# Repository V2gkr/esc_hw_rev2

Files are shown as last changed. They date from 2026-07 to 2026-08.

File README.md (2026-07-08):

# ESC HW Rev2 - E-Bike BLDC Motor Driver

Rev2 hardware for an electronic speed controller (ESC) for an e-bike. Designed in KiCad.

## Key Specifications

| Parameter | Value |
|---|---|
| Nominal battery voltage | 36 V |
| Nominal motor power | 250 W |
| MCU | STM32G431CBT6 |
| Gate driver | DRV8320S |
| Phase current sensing |  low-side shunts |
| Rotor position feedback | Hall sensors |
| Interfaces | CAN FD, UART |
| Indication | LEDs (Green / Red) |
| Control | Reset button |

## Board Architecture

The project is split into several KiCad hierarchical schematic sheets:

- **MCU.kicad_sch** - STM32G431CBT6 support circuitry: power supply, crystals, debug interface, reset button, LEDs.
- **Power.kicad_sch** - 36 V input power stage, protection, DC/DC converters for logic and gate driver supply.
- **Inverter.kicad_sch** - three-phase power inverter stage based on DRV8320S and power MOSFETs.
- **Measurements.kicad_sch** - phase current sensing circuitry (3 low-side shunts) and Hall sensor interfaces.
- **CAN.kicad_sch** - CAN FD transceiver and supporting circuitry.
- **BLDC_Test.kicad_sch / BLDC_Test.kicad_pcb / BLDC_Test.kicad_pro** - top-level schematic and PCB layout tying all sheets above together.

## Key Subsystems

### Power Stage
Three-phase MOSFET inverter driven by the **DRV8320S** gate driver (built-in protection: overtemperature, overcurrent, gate drive undervoltage, etc.).

### Current and Rotor Position Sensing
- 3 low-side shunts - phase current measurement for FOC/trapezoidal commutation and overcurrent protection.
- Hall sensors - rotor position detection for low-speed commutation and start-up under load.

### Communication Interfaces
- **CAN FD** - primary control/telemetry channel (e.g. integration with a BMS or a central e-bike controller).
- **UART** - debugging, logging, alternative control/flashing channel.

### Indication and Control
- Green / Red LEDs - status indication (ready, fault, CAN activity, etc. â€” defined by firmware).
- Reset button - hardware MCU reset.

## Project Status

Hardware only (rev2). Firmware is maintained in a separate repository (see [`esc_fw_rev2`](https://github.com/V2gkr/esc_fw_rev2/tree/main)).

## TODO
- [ ] Export schematics to PDF for quick viewing without KiCad
- [ ] Bill of Materials (BOM)
- [ ] Board photos/renders
- [ ] Datasheet links for key components (DRV8320S, STM32G431CBT6)

## Tools
Designed in **KiCad**.

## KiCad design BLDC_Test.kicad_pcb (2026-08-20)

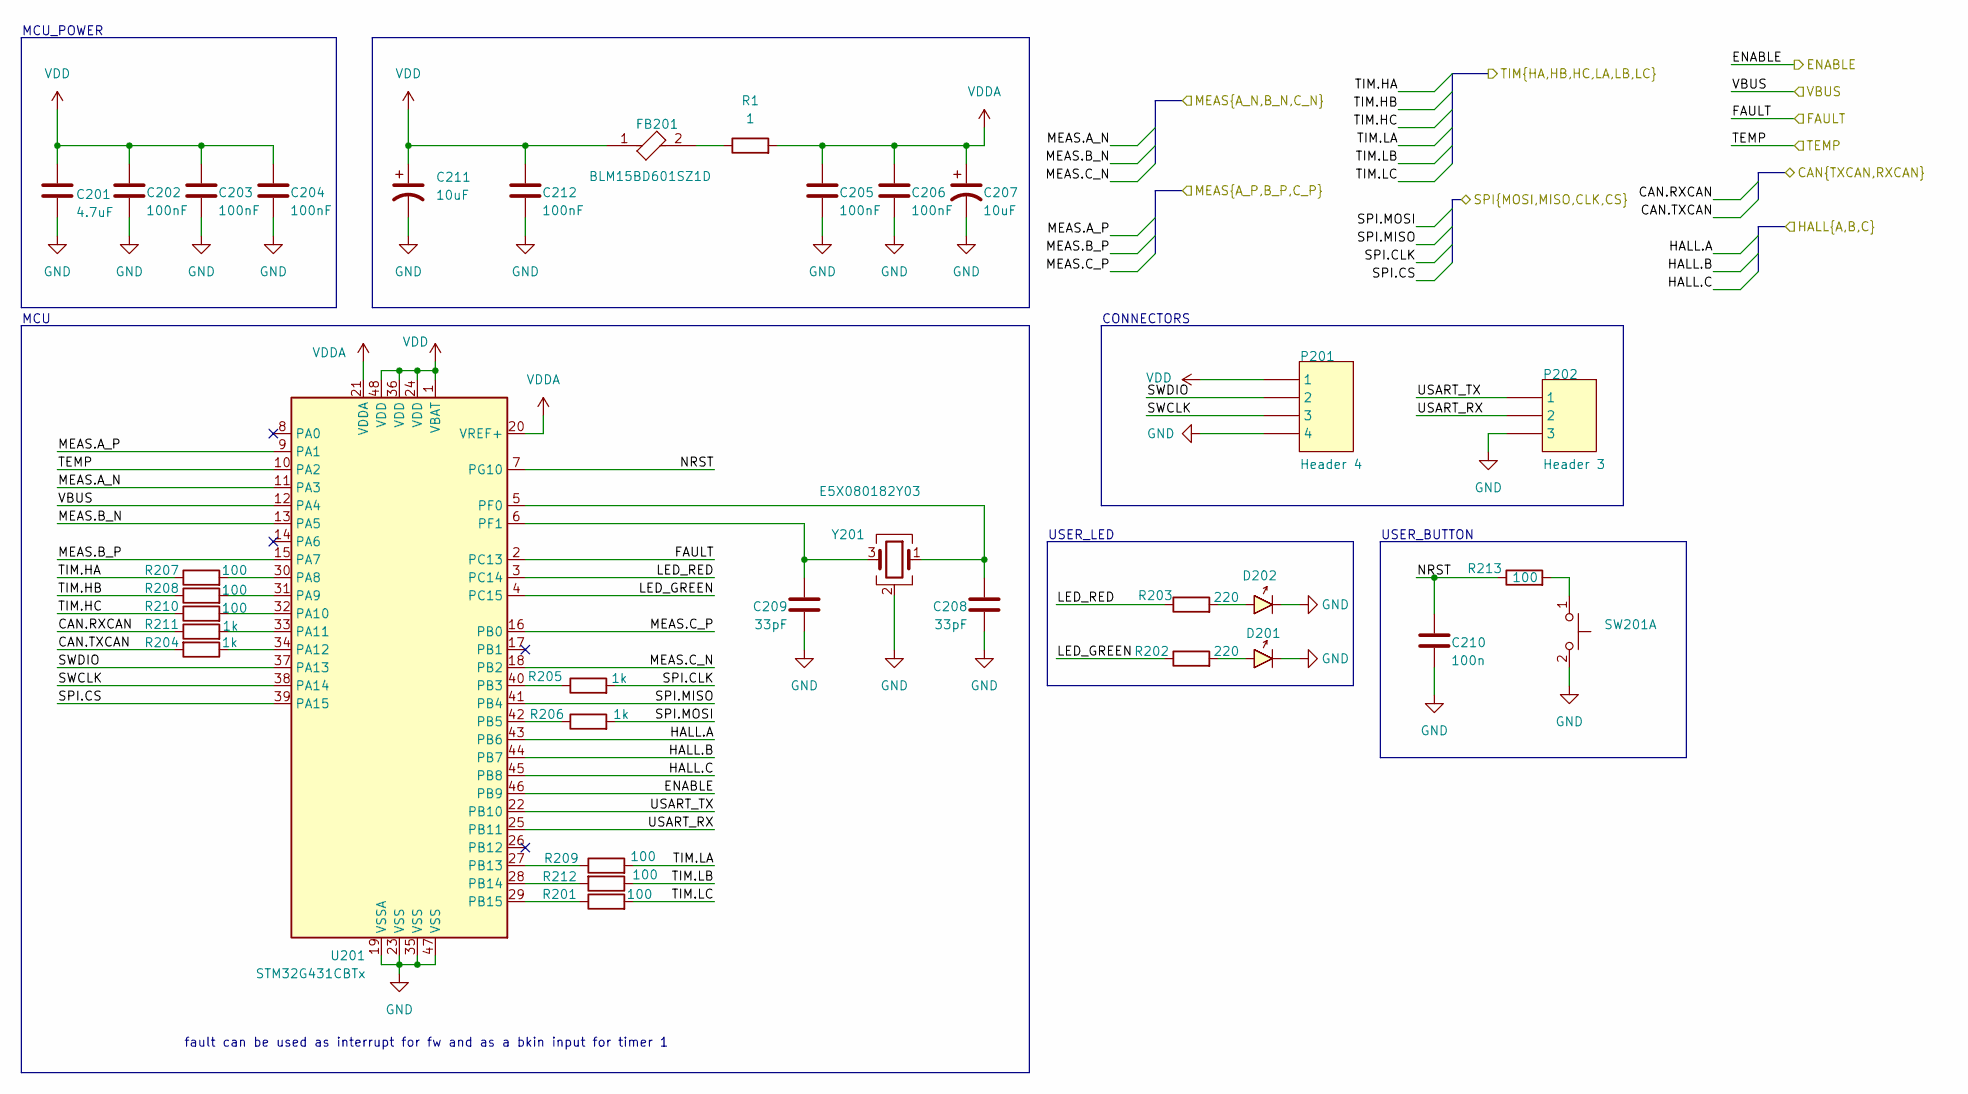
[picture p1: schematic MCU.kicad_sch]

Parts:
C201: 4.7uF; C_0603_1608Metric_Pad1.08x0.95mm_HandSolder
C202, C203, C204, C205, C206, C212: 100nF; C_0603_1608Metric_Pad1.08x0.95mm_HandSolder
C207, C211: 10uF; CP_EIA-2012-15_AVX-P_HandSolder
C208, C209: 33pF; C_0603_1608Metric_Pad1.08x0.95mm_HandSolder
C210: 100n; C_0603_1608Metric_Pad1.08x0.95mm_HandSolder
D201, D202: Common diode; LED_0603_1608Metric_Pad1.05x0.95mm_HandSolder; REVERSE VOLTAGE 1000V; MANUFACTURER PART NUMBER US1M-E3/61T; DIGIKEY DESCRIPTION DIODE GEN PURP 1KV 1A DO214AC
FB201: BLM15BD601SZ1D; L_0603_1608Metric_Pad1.05x0.95mm_HandSolder
P201: Header 4; PinHeader_1x04_P2.54mm_Vertical
P202: Header 3; PinHeader_1x03_P2.54mm_Vertical
R1: 1; R_0603_1608Metric_Pad0.98x0.95mm_HandSolder
R201, R207, R208, R209, R210, R212, R213: 100; R_0603_1608Metric_Pad0.98x0.95mm_HandSolder
R202, R203: 220; R_0603_1608Metric_Pad0.98x0.95mm_HandSolder
R204, R205, R206, R211: 1k; R_0603_1608Metric_Pad0.98x0.95mm_HandSolder
SW201: PTS647SM38SMTR2LFS; SW_SPST_TL3305A; RATINGS IP40
U201: STM32G431CBTx; LQFP-48_7x7mm_P0.5mm
Y201: E5X080182Y03; Crystal_SMD_WE_CFPX-104-4Pin_5.0x3.2mm; FREQUENCY TOLERANCE 0.07%

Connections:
/can/CAN.RXCAN: R211.1; also elsewhere on the board
/can/CAN.TXCAN: R204.2; also elsewhere on the board
/inverter/ENABLE: U201.46 (PB9); also elsewhere on the board
/inverter/FAULT: U201.2 (PC13); also elsewhere on the board
/inverter/MEAS.A_N: U201.11 (PA3); also elsewhere on the board
/inverter/MEAS.B_N: U201.13 (PA5); also elsewhere on the board
/inverter/MEAS.C_N: U201.18 (PB2); also elsewhere on the board
/inverter/SPI.CLK: R205.2; also elsewhere on the board
/inverter/SPI.CS: U201.39 (PA15); also elsewhere on the board
/inverter/SPI.MISO: U201.41 (PB4); also elsewhere on the board
/inverter/SPI.MOSI: R206.2; also elsewhere on the board
/inverter/TIM.HA: R207.1; also elsewhere on the board
/inverter/TIM.HB: R208.1; also elsewhere on the board
/inverter/TIM.HC: R210.1; also elsewhere on the board
/inverter/TIM.LA: R209.2; also elsewhere on the board
/inverter/TIM.LB: R212.1; also elsewhere on the board
/inverter/TIM.LC: R201.2; also elsewhere on the board
/mcu/HALL.A: U201.43 (PB6); also elsewhere on the board
/mcu/HALL.B: U201.44 (PB7); also elsewhere on the board
/mcu/HALL.C: U201.45 (PB8); also elsewhere on the board
/mcu/LED_GREEN: R202.1, U201.4 (PC15)
/mcu/LED_RED: R203.1, U201.3 (PC14)
/mcu/MEAS.A_P: U201.9 (PA1); also elsewhere on the board
/mcu/MEAS.B_P: U201.15 (PA7); also elsewhere on the board
/mcu/MEAS.C_P: U201.16 (PB0); also elsewhere on the board
/mcu/NRST: C210.1, R213.1, U201.7 (PG10)
/mcu/SWCLK: P201.3, U201.38 (PA14)
/mcu/SWDIO: P201.2, U201.37 (PA13)
/mcu/TEMP: U201.10 (PA2); also elsewhere on the board
/mcu/USART_RX: P202.2, U201.25 (PB11)
/mcu/USART_TX: P202.1, U201.22 (PB10)
/mcu/VBUS: U201.12 (PA4); also elsewhere on the board
GND: C201.2, C202.2, C203.2, C204.2, C205.2, C206.2, C207.2, C208.2, C209.2, C210.2, C211.2, C212.2, D201.1 (C), D202.1 (C), P201.4, P202.3, SW201.2 (D), U201.19 (VSSA), U201.23 (VSS), U201.35 (VSS), U201.47 (VSS), Y201.2 (G), Y201.4 (G); also elsewhere on the board
unnamed: D201.2 (A), R202.2
unnamed: D202.2 (A), R203.2
unnamed: FB201.2, R1.1
unnamed: R213.2, SW201.1 (C)
unnamed: R207.2, U201.30 (PA8)
unnamed: R208.2, U201.31 (PA9)
unnamed: R210.2, U201.32 (PA10)
unnamed: R211.2, U201.33 (PA11)
unnamed: R204.1, U201.34 (PA12)
unnamed: R205.1, U201.40 (PB3)
unnamed: R206.1, U201.42 (PB5)
unnamed: R209.1, U201.27 (PB13)
unnamed: R212.2, U201.28 (PB14)
unnamed: R201.1, U201.29 (PB15)
unnamed: C208.1, U201.5 (PF0), Y201.1
unnamed: C209.1, U201.6 (PF1), Y201.3
VDD: C201.1, C202.1, C203.1, C204.1, C211.1, C212.1, FB201.1, P201.1, U201.1 (VBAT), U201.24 (VDD), U201.36 (VDD), U201.48 (VDD); also elsewhere on the board
VDDA: C205.1, C206.1, C207.1, R1.2, U201.20 (VREF+), U201.21 (VDDA); also elsewhere on the board

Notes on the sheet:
USER_LED
MCU_POWER
CONNECTORS
USER_BUTTON
MCU
fault can be used as interrupt for fw and as a bkin input for timer 1

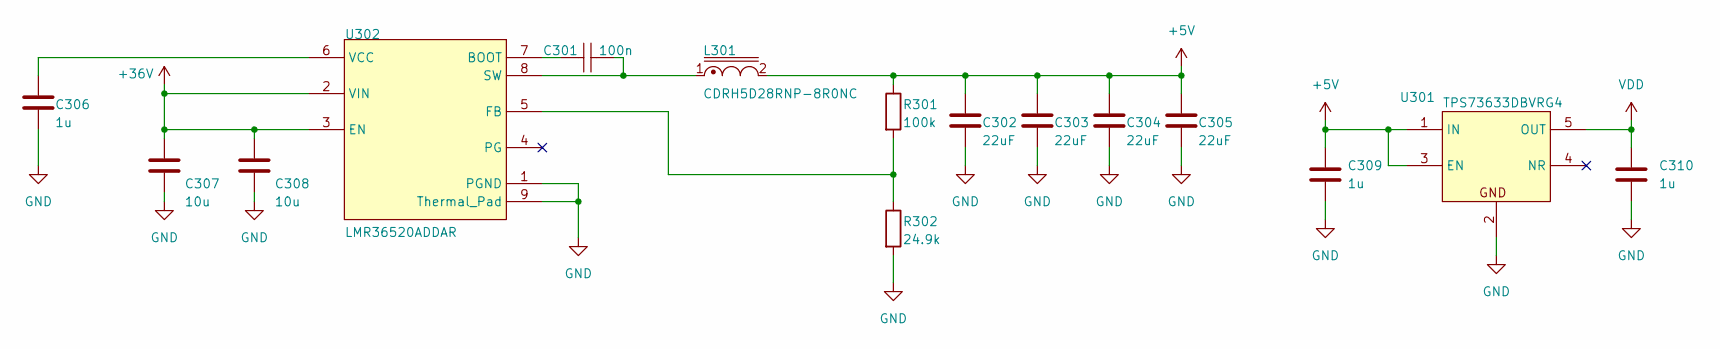
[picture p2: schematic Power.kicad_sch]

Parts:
C301: 100n; C_0603_1608Metric_Pad1.08x0.95mm_HandSolder
C302, C303, C304, C305: 22uF; C_0805_2012Metric_Pad1.18x1.45mm_HandSolder
C306, C309, C310: 1u; C_0603_1608Metric_Pad1.08x0.95mm_HandSolder
C307, C308: 10u; C_0805_2012Metric_Pad1.18x1.45mm_HandSolder
L301: CDRH5D28RNP-8R0NC; MANUFACTURER PART NUMBER PA4320.153NLT
R301: 100k; R_0603_1608Metric_Pad0.98x0.95mm_HandSolder
R302: 24.9k; R_0603_1608Metric_Pad0.98x0.95mm_HandSolder
U301: TPS73633DBVRG4; SOT-23-5_HandSoldering; RATING Catalog; PARTNUMBER TPS73633DBVRG4
U302: LMR36520ADDAR; FP-DDA0008J-IPC_B

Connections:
+5V: C302.1, C303.1, C304.1, C305.1, C309.1, L301.2, R301.1, U301.1 (IN), U301.3 (EN); also elsewhere on the board
+36V: C307.1, C308.1, U302.2 (VIN), U302.3 (EN); also elsewhere on the board
GND: C302.2, C303.2, C304.2, C305.2, C306.2, C307.2, C308.2, C309.2, C310.2, R302.2, U301.2 (GND), U302.1 (PGND), U302.9 (Thermal_Pad); also elsewhere on the board
unnamed: C301.2, U302.7 (BOOT)
unnamed: R301.2, R302.1, U302.5 (FB)
unnamed: C301.1, L301.1, U302.8 (SW)
unnamed: C306.1, U302.6 (VCC)
VDD: C310.1, U301.5 (OUT); also elsewhere on the board

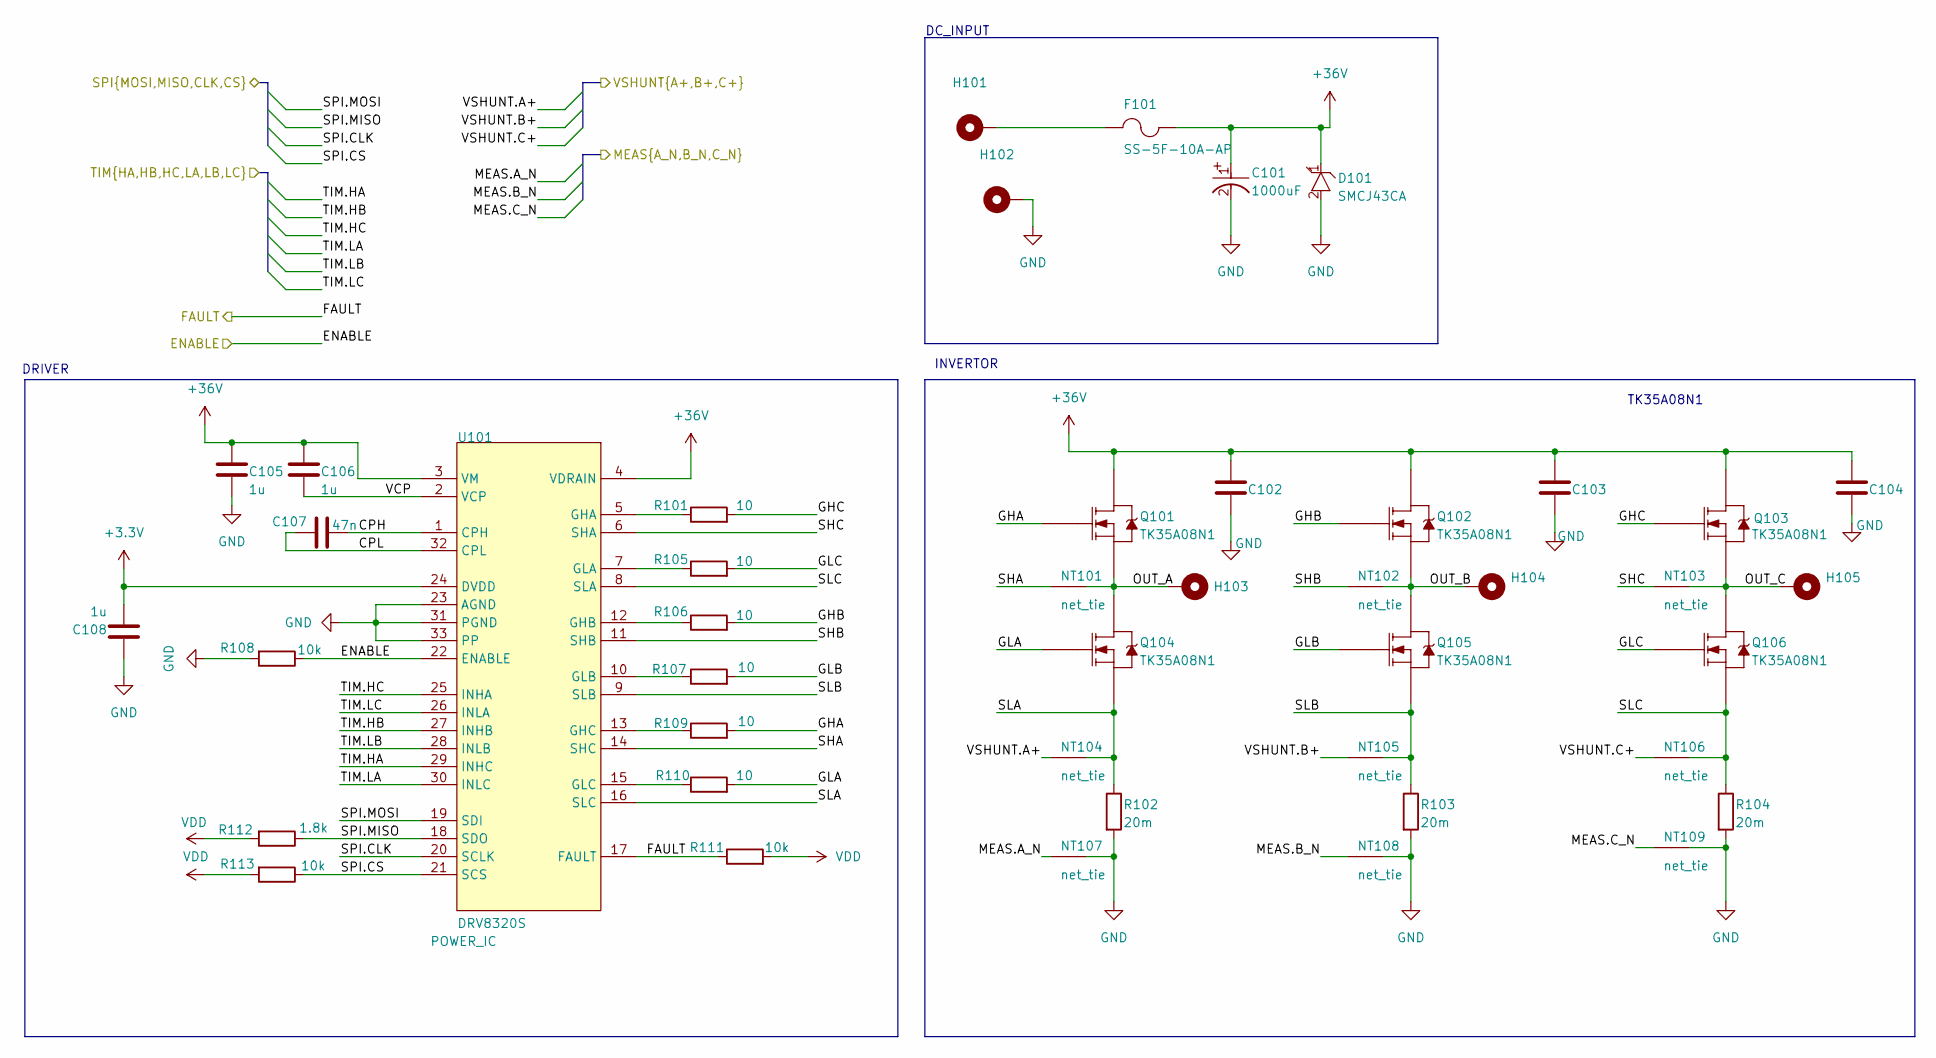
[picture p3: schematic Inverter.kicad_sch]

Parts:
C101: 1000uF; PCAP_7_5mm; VOLTAGE RATING (DC) 50V; TOLERANCE 20%; MANUFACTURER PART NUMBER EEUFM1H471
C102, C103, C104: 1812B105K101CT; C_1812_4532Metric_Pad1.57x3.40mm_HandSolder
C105: 1u; C_1210_3225Metric_Pad1.33x2.70mm_HandSolder
C106, C108: 1u; C_0603_1608Metric_Pad1.08x0.95mm_HandSolder
C107: 47n; C_0603_1608Metric_Pad1.08x0.95mm_HandSolder
D101: SMCJ43CA; D_SMC; REVERSE VOLTAGE 1000V; MANUFACTURER PART NUMBER US1M-E3/61T; DIGIKEY DESCRIPTION DIODE GEN PURP 1KV 1A DO214AC
F101: SS-5F-10A-AP; FUSE_SS-5F_COB; MANUFACTURER_PART_NUMBER SS-5F-1.25A-AP
H101, H102, H103, H104, H105: phase connector; phase_cable_soldering_hole
NT101, NT102, NT103: net_tie; NetTie-2_SMD_Pad0.5mm
NT104, NT105, NT106, NT107, NT108, NT109: net_tie; NetTie-2_SMD_Pad0.3mm
Q101, Q102, Q103, Q104, Q105, Q106: TK35A08N1; TO-220-3_Vertical
R101, R105, R106, R107, R109, R110: 10; R_0603_1608Metric_Pad0.98x0.95mm_HandSolder
R102, R103, R104: 20m; R_2512_6332Metric_Pad1.40x3.35mm_HandSolder
R108, R111, R113: 10k; R_0603_1608Metric_Pad0.98x0.95mm_HandSolder
R112: 1.8k; R_0603_1608Metric_Pad0.98x0.95mm_HandSolder
U101: DRV8320S; QFN50P500X500X80-33N

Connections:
+3.3V: C108.2, U101.24 (DVDD)
+36V: C101.1 (A), C102.1, C103.1, C104.1, C105.1, C106.1, D101.1 (C), F101.2, Q101.2 (D), Q102.2 (D), Q103.2 (D), U101.3 (VM), U101.4 (VDRAIN); also elsewhere on the board
/inverter/CPH: C107.2, U101.1 (CPH)
/inverter/CPL: C107.1, U101.32 (CPL)
/inverter/ENABLE: R108.1, U101.22 (ENABLE); also elsewhere on the board
/inverter/FAULT: R111.1, U101.17 (FAULT); also elsewhere on the board
/inverter/GHA: Q101.1 (G), R109.2
/inverter/GHB: Q102.1 (G), R106.2
/inverter/GHC: Q103.1 (G), R101.2
/inverter/GLA: Q104.1 (G), R110.2
/inverter/GLB: Q105.1 (G), R107.2
/inverter/GLC: Q106.1 (G), R105.2
/inverter/MEAS.A_N: NT107.2; also elsewhere on the board
/inverter/MEAS.B_N: NT108.2; also elsewhere on the board
/inverter/MEAS.C_N: NT109.2; also elsewhere on the board
/inverter/OUT_A: H103.1 (1_1), NT101.1, Q101.3 (S), Q104.2 (D)
/inverter/OUT_B: H104.1 (1_1), NT102.1, Q102.3 (S), Q105.2 (D)
/inverter/OUT_C: H105.1 (1_1), NT103.1, Q103.3 (S), Q106.2 (D)
/inverter/SHA: NT101.2, U101.14 (SHC)
/inverter/SHB: NT102.2, U101.11 (SHB)
/inverter/SHC: NT103.2, U101.6 (SHA)
/inverter/SLA: NT104.1, Q104.3 (S), R102.1, U101.16 (SLC)
/inverter/SLB: NT105.1, Q105.3 (S), R103.1, U101.9 (SLB)
/inverter/SLC: NT106.1, Q106.3 (S), R104.1, U101.8 (SLA)
/inverter/SPI.CLK: U101.20 (SCLK); also elsewhere on the board
/inverter/SPI.CS: R113.1, U101.21 (SCS); also elsewhere on the board
/inverter/SPI.MISO: R112.1, U101.18 (SDO); also elsewhere on the board
/inverter/SPI.MOSI: U101.19 (SDI); also elsewhere on the board
/inverter/TIM.HA: U101.29 (INHC); also elsewhere on the board
/inverter/TIM.HB: U101.27 (INHB); also elsewhere on the board
/inverter/TIM.HC: U101.25 (INHA); also elsewhere on the board
/inverter/TIM.LA: U101.30 (INLC); also elsewhere on the board
/inverter/TIM.LB: U101.28 (INLB); also elsewhere on the board
/inverter/TIM.LC: U101.26 (INLA); also elsewhere on the board
/inverter/VCP: C106.2, U101.2 (VCP)
/inverter/VSHUNT.A+: NT104.2; also elsewhere on the board
/inverter/VSHUNT.B+: NT105.2; also elsewhere on the board
/inverter/VSHUNT.C+: NT106.2; also elsewhere on the board
GND: C101.2 (B), C102.2, C103.2, C104.2, C105.2, C108.1, D101.2 (A), H102.1 (1_1), NT107.1, NT108.1, NT109.1, R102.2, R103.2, R104.2, R108.2, U101.23 (AGND), U101.31 (PGND), U101.33 (PP); also elsewhere on the board
unnamed: F101.1, H101.1 (1_1)
unnamed: R101.1, U101.5 (GHA)
unnamed: R106.1, U101.12 (GHB)
unnamed: R109.1, U101.13 (GHC)
unnamed: R105.1, U101.7 (GLA)
unnamed: R107.1, U101.10 (GLB)
unnamed: R110.1, U101.15 (GLC)
VDD: R111.2, R112.2, R113.2; also elsewhere on the board

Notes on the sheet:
TK35A08N1
INVERTOR
DRIVER
DC_INPUT

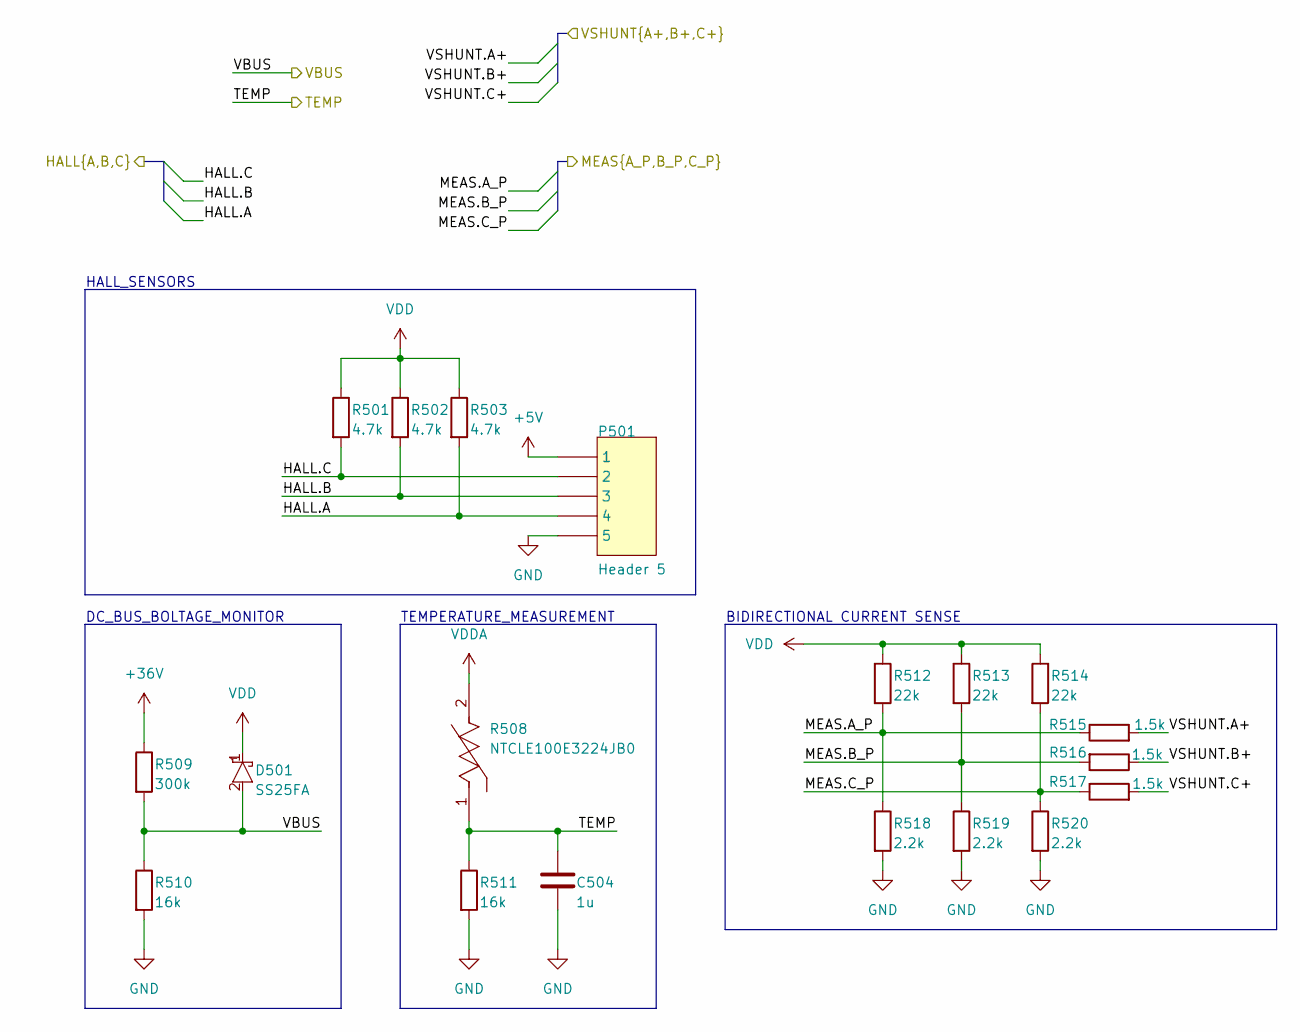
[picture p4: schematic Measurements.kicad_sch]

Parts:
C504: 1u; C_0603_1608Metric_Pad1.08x0.95mm_HandSolder
D501: SS25FA; D_SOD-323; REVERSE VOLTAGE 1000V; MANUFACTURER PART NUMBER US1M-E3/61T; DIGIKEY DESCRIPTION DIODE GEN PURP 1KV 1A DO214AC
P501: Header 5; PinHeader_1x05_P2.54mm_Vertical
R501, R502, R503: 4.7k; R_0603_1608Metric_Pad0.98x0.95mm_HandSolder
R508: NTCLE100E3224JB0; FP-NTCLE100E3224JB0-MFG; TOLERANCE 5%; RESISTANCE TOLERANCE 5%
R509: 300k; R_0603_1608Metric_Pad0.98x0.95mm_HandSolder
R510, R511: 16k; R_0603_1608Metric_Pad0.98x0.95mm_HandSolder
R512, R513, R514: 22k; R_0603_1608Metric_Pad0.98x0.95mm_HandSolder
R515, R516, R517: 1.5k; R_0603_1608Metric_Pad0.98x0.95mm_HandSolder
R518, R519, R520: 2.2k; R_0603_1608Metric_Pad0.98x0.95mm_HandSolder

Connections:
+5V: P501.1; also elsewhere on the board
+36V: R509.1; also elsewhere on the board
/inverter/VSHUNT.A+: R515.2; also elsewhere on the board
/inverter/VSHUNT.B+: R516.1; also elsewhere on the board
/inverter/VSHUNT.C+: R517.2; also elsewhere on the board
/mcu/HALL.A: P501.4, R503.2; also elsewhere on the board
/mcu/HALL.B: P501.3, R502.2; also elsewhere on the board
/mcu/HALL.C: P501.2, R501.2; also elsewhere on the board
/mcu/MEAS.A_P: R512.2, R515.1, R518.1; also elsewhere on the board
/mcu/MEAS.B_P: R513.2, R516.2, R519.1; also elsewhere on the board
/mcu/MEAS.C_P: R514.2, R517.1, R520.1; also elsewhere on the board
/mcu/TEMP: C504.1, R508.1, R511.1; also elsewhere on the board
/mcu/VBUS: D501.2 (A), R509.2, R510.1; also elsewhere on the board
GND: C504.2, P501.5, R510.2, R511.2, R518.2, R519.2, R520.2; also elsewhere on the board
VDD: D501.1 (C), R501.1, R502.1, R503.1, R512.1, R513.1, R514.1; also elsewhere on the board
VDDA: R508.2; also elsewhere on the board

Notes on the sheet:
HALL_SENSORS
DC_BUS_BOLTAGE_MONITOR
BIDIRECTIONAL CURRENT SENSE
TEMPERATURE_MEASUREMENT

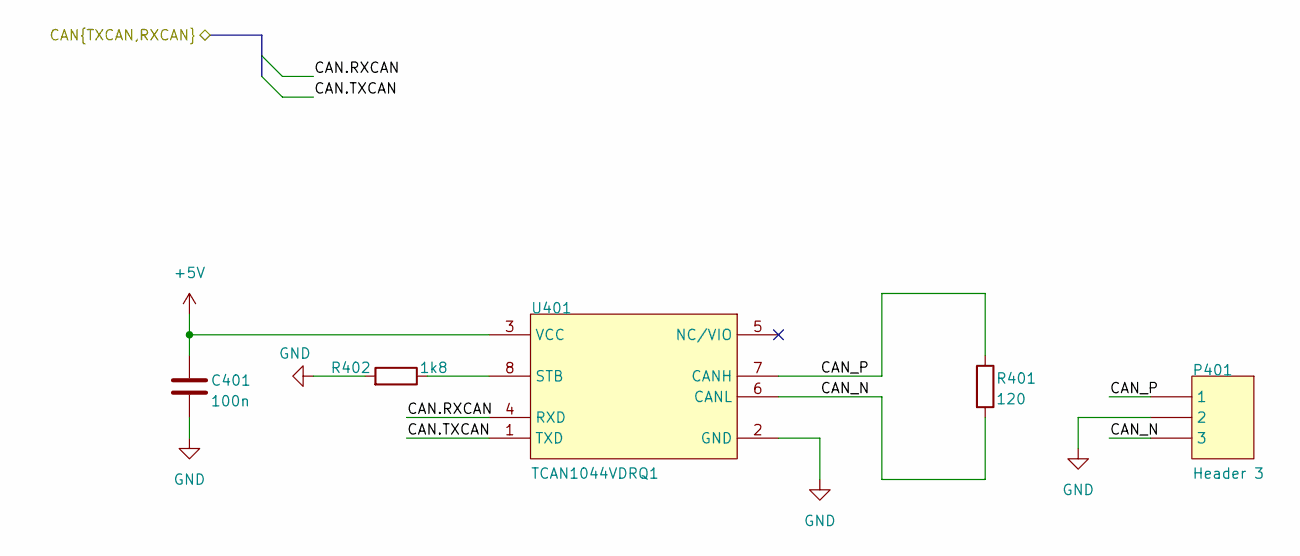
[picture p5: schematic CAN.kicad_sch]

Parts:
C401: 100n; C_0603_1608Metric_Pad1.08x0.95mm_HandSolder
P401: Header 3; PinHeader_1x03_P2.54mm_Vertical
R401: 120; R_0603_1608Metric_Pad0.98x0.95mm_HandSolder
R402: 1k8; R_0603_1608Metric_Pad0.98x0.95mm_HandSolder
U401: TCAN1044VDRQ1; SO-8_3.9x4.9mm_P1.27mm

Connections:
+5V: C401.1, U401.3 (VCC); also elsewhere on the board
/can/CAN.RXCAN: U401.4 (RXD); also elsewhere on the board
/can/CAN.TXCAN: U401.1 (TXD); also elsewhere on the board
/can/CAN_N: P401.3, R401.2, U401.6 (CANL)
/can/CAN_P: P401.1, R401.1, U401.7 (CANH)
GND: C401.2, P401.2, R402.2, U401.2 (GND); also elsewhere on the board
unnamed: R402.1, U401.8 (STB)

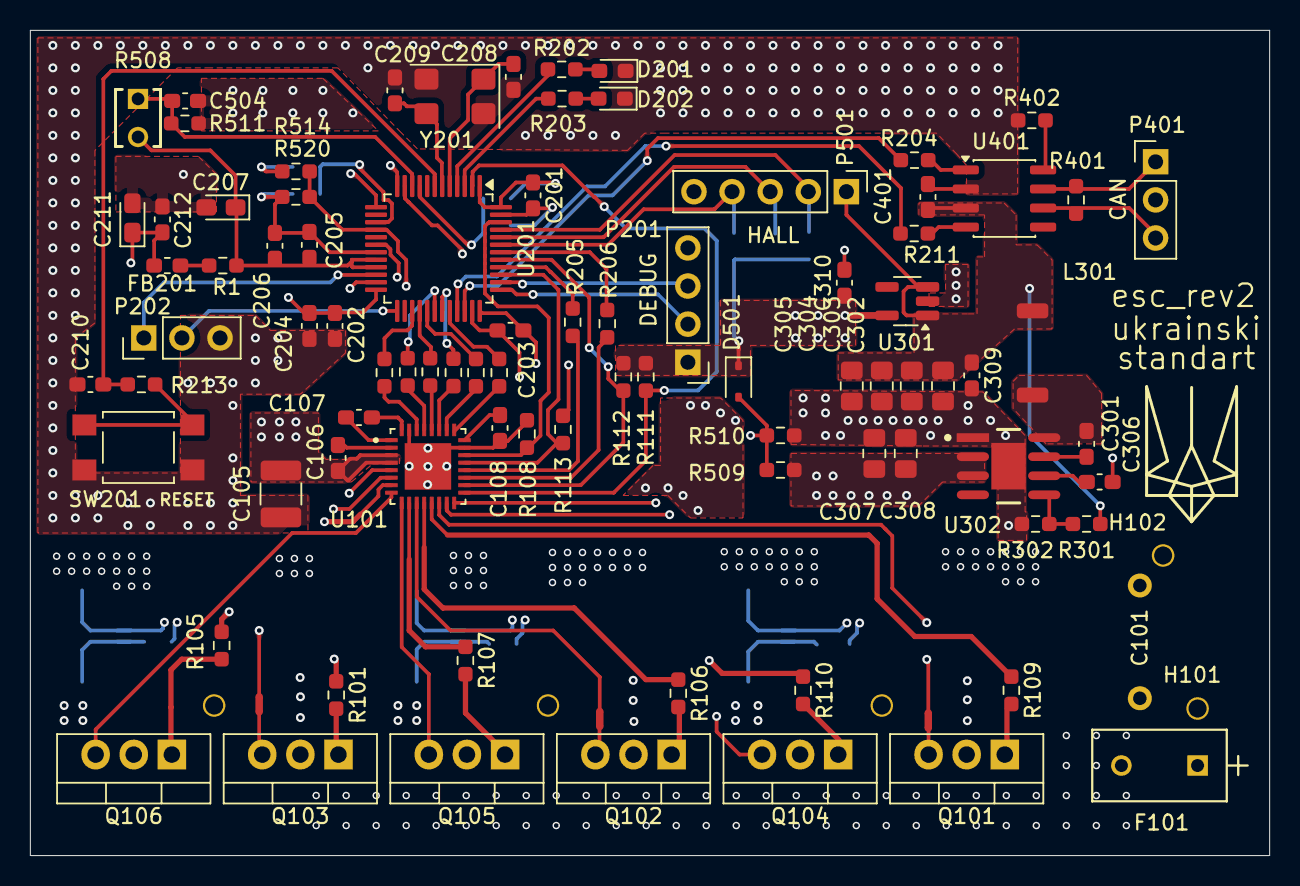
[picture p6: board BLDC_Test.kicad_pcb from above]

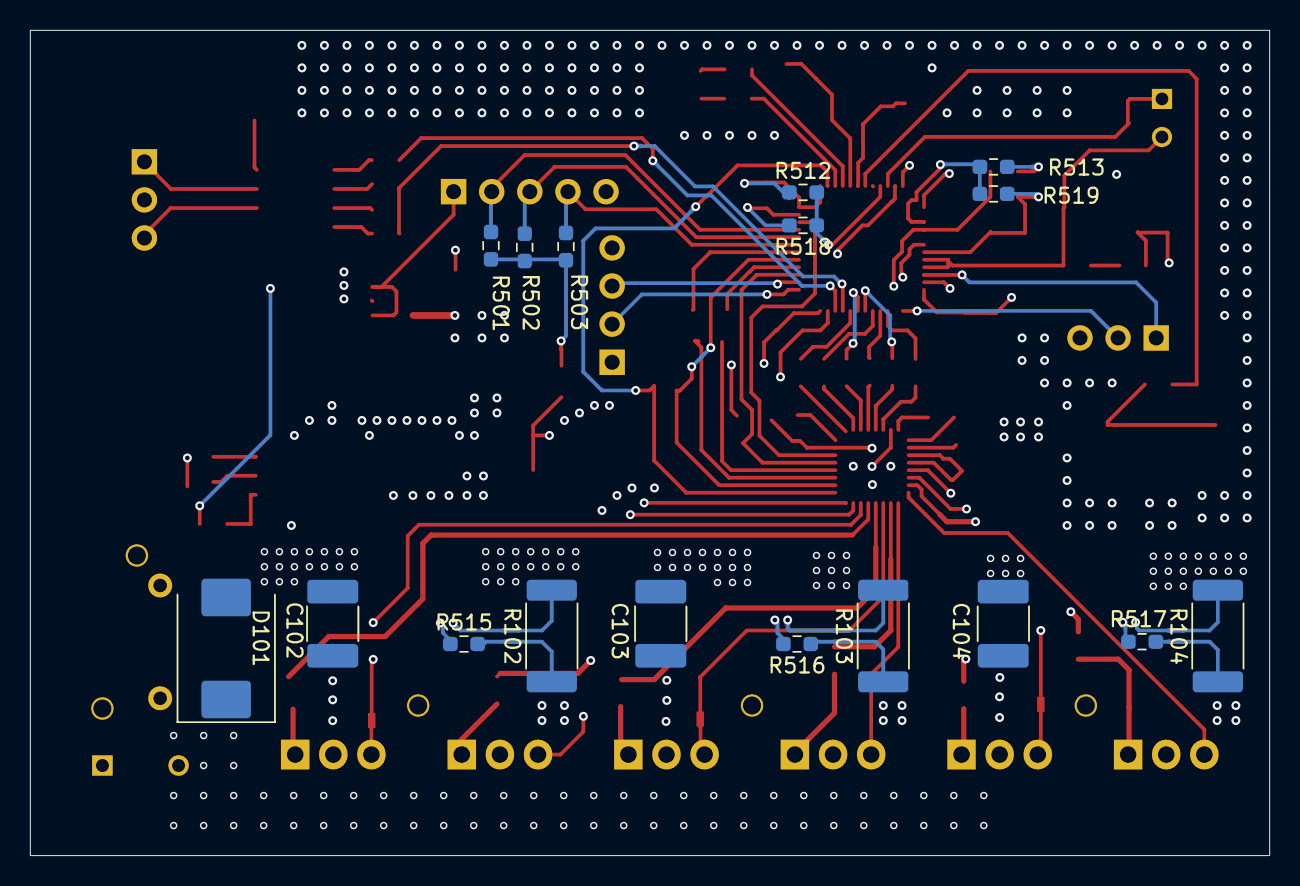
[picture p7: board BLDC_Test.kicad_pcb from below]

Board: 6 copper layers, 82.6 x 55.0 mm, 117 parts (23 on the bottom side), 89 nets.

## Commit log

2026-02-26 added names to sheets
    [BLDC_Test.kicad_sch, Inverter.kicad_sch]
2026-02-26 changed nets
    [CAN.kicad_sch, Inverter.kicad_sch, MCU.kicad_sch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]
2026-02-27 changed schematic and pcb to kicad style
    [BLDC_Test.kicad_pcb, CAN.kicad_sch, Inverter.kicad_sch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]
2026-02-27 changed phases a and c
    [BLDC_Test.kicad_pcb, CAN.kicad_sch, Inverter.kicad_sch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]
2026-03-01 routed power polygons
    [BLDC_Test.kicad_pcb, Inverter.kicad_sch, MCU.kicad_sch]
2026-03-05 completed routing
    [BLDC_Test.kicad_pcb, CAN.kicad_sch, Inverter.kicad_sch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]
2026-03-06 fixed small errors in schematic
    [MCU.kicad_sch, Power.kicad_sch]
2026-03-09 fixed errors from review
    [BLDC_Test.kicad_pcb, CAN.kicad_sch, Inverter.kicad_sch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]
2026-03-10 final changes and sending to production
    [BLDC_Test.kicad_pcb, Inverter.kicad_sch, MCU.kicad_sch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]
2026-08-18 partnum fix
    [BLDC_Test.kicad_sch, CAN.kicad_sch, Inverter.kicad_sch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]
2026-08-19 updated pcb properties
    [BLDC_Test.kicad_pcb, Power.kicad_sch]
2026-08-20 updated schematic
    [BLDC_Test.kicad_pcb, BLDC_Test.kicad_sch, CAN.kicad_sch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]

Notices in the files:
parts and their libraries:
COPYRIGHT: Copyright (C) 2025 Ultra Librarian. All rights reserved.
